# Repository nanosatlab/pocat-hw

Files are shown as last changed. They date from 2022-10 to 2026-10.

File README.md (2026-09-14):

# 3CatNXT PocketQube — Hardware

Hardware repository for the IEEE GRSS PocketQube built at the [NanoSat Lab (UPC)](https://nanosatlab.upc.edu/).

It holds the complete electrical and mechanical design of the satellite: KiCad projects for every
PCB in the stack, the SolidWorks/STEP assembly of the full spacecraft, the deployment mechanisms,
and the ground/mechanical support equipment used to integrate and test it.

This repository contains **design data only** — there is nothing to build or run. Flight and
ground software live elsewhere, as does the PL3 payload hardware
([nanosatlab/pocat-rfi-5g](https://github.com/nanosatlab/pocat-rfi-5g)).

---

## Repository layout

| Path | What it is |
|---|---|
| `pq_eps/` | Electrical Power Subsystem |
| `pq_obc_comms/` | On-Board Computer + COMMS transceiver |
| `pq_adcs/` | Attitude Determination and Control System |
| `pq_pl1/` | Payload 1 interface board |
| `pq_pl2/` | Payload 2 — L-band receiver |
| `pq_topboard/` | +Z face board |
| `pq_botboard/` | −Z face board |
| `pq_latboard/` | Lateral (side) face board |
| `pq_ymag_board/` | +Y magnetorquer board |
| `pq_botnotsobot/` | Deployment-switch / slider board |
| `pq_egse/` | EGSE — electrical ground support equipment breakout |
| `assembly/` | SolidWorks + STEP mechanical assembly of the whole satellite |
| `Vitrina_PQ/` | Display case (acrylic showcase) for the engineering model |

Each KiCad project directory typically contains the `.kicad_sch` / `.kicad_pcb` / `.kicad_pro`
triplet, an exported `.step` for mechanical integration, and a `production/` folder with the IPC
netlist and (where fabricated) Gerbers. Directories suffixed `_old` are superseded revisions kept
for traceability; `pq_pl2/Imports/` holds the original Altium design that PL2 was migrated from.

---

## The boards

The satellite is a stack of 40 × 40 mm boards held between structural face boards that also carry
the solar cells and thermal sensors.

### Stack boards (40 × 40 mm)

**`pq_eps` — Electrical Power Subsystem** · 4-layer, 1.6 mm

Solar energy harvesting through **SPV1040** MPPT boost converters, battery charging and
power-path management by an **LTC4040**, coulomb counting via a **DS2782** fuel gauge, and
regulated rails from an **ISL9120** buck-boost. Carries the kill-switch logic that gates the
main regulator, plus the antenna burn-wire release (`BURNCOMMS`) and per-rail enables for the
ADCS and payloads. Battery is a single Li-ion **LP14430** cell.

**`pq_obc_comms` — On-Board Computer & COMMS** · 4-layer, 1.6 mm

**STM32L476RGT6** microcontroller with a 32 MHz TCXO and a 32.768 kHz RTC crystal, paired with a
**SX1262** sub-GHz LoRa transceiver. RF front end uses a **BGS12PL6** antenna switch out to U.FL
and MS-156C test connectors. The STM32CubeMX pin configuration lives alongside the project in
`STM32L476RG_config/STM32L476RG_config.ioc`, and an interactive BOM is generated at
`pq_obc_comms/bom/ibom.html`.

**`pq_adcs` — Attitude Determination & Control** · 6-layer, 1.6 mm

Sensing from an **IIM-42652** 6-axis IMU and an **MMC5983MA** magnetometer, with sun-sensor
conditioning through **LPV542** op-amps and a **TMUX1108** analog multiplexer.

Two revisions are tracked:
- `PQ_ADCS/` — original design, magnetorquer coils driven by a **BD2606MVV**.
- `PQ_ADCS_HBridge/` — current revision, redesigned around **DRV8214** H-bridge drivers. The
  vendor-supplied symbol, footprint and STEP for the DRV8214 are vendored in
  `PQ_ADCS_HBridge/DRV8214RTER/`.

**`pq_pl2` — L-band receiver payload** · 4-layer, 1.58 mm

Full receive chain: **BFCG162W** LNA → **LEE2-6+** gain stage → **MAX2121** direct-conversion
tuner, with an **LT5537** RF power detector for level monitoring and an **LT3048** ultra-low-noise
LDO feeding the RF section. Clocked by an **ECS-TXO-2016MV** TCXO; MS-156C and U.FL connectors
provide antenna and test access.

**`pq_pl1` — Payload 1 interface** · 2-layer, 1.6 mm

Passive interface/adapter board exposing the stack connector to the PL1 experiment.

### Face and structural boards

**`pq_topboard` / `pq_botboard` / `pq_latboard`** · 2-, 6- and 6-layer respectively

These form the outer faces of the cube. They mount **SLCD-61N8** solar cells and **TCN75A**
digital temperature sensors, and route the harness into the stack. The bottom board additionally
carries **TPS7A7001/7002** LDOs, and the lateral board brings out coaxial connectors for the
deployable antenna. Face boards are 2 mm thick because they are structural.

**`pq_ymag_board`** · 6-layer, 2 mm, 45 × 45 mm

+Y magnetorquer — an air-core coil etched into the PCB, driven from the ADCS board.

**`pq_botnotsobot`** · 2-layer, 1.6 mm, 64 × 58 mm

Slider board carrying the **D2FLA** deployment/kill switches that hold the satellite inert inside
the deployer.

**`pq_egse`** · 6-layer

Electrical Ground Support Equipment. A large breakout fixture that fans every stack connector out
to 0.1" headers so subsystems can be probed, powered and stimulated individually on the bench.
Fabrication Gerbers and drill files are checked in under `pq_egse/manufacturing/`.

---

## Mechanical assembly

`assembly/` is the SolidWorks model of the integrated spacecraft. The top-level assemblies are:

- `ieee_grss_pocketqube.SLDASM` — the full satellite.
- `ieee_grss_pocketqube_beta antena.SLDASM` — variant with the deployed antenna configuration.

Supporting content is organised by subsystem — `eps/`, `adcs/`, `obc&comms/`, `payloads/`,
`structure/`, `lateral/`, `bottom/`, `slider/` — and each PCB folder carries the board as both a
`.step` and a `.SLDPRT`, together with the Edge_Cuts and silkscreen DXF/SVG exports used to keep
the mechanical model in sync with the electrical design.

Of note:

- **`assembly/lateral/antena-deployment/`** — the COMMS tape-spring antenna and its burn-wire
  release: turret, pivot, spring, clip and the resistor that cuts the restraint.
- **`assembly/Lband_Deployment_Mechanism/`** — deployment mechanism for the L-band payload
  antenna (`Lband3d_2res_v7.2.SLDASM`), with its own board and antenna sub-assemblies and a
  `STEP_files/` export set.
- **`assembly/payloads/pl3/`** — RFI-5G payload structure (antenna, supports, SMP interface).
  Mechanical only — the PL3 electrical design lives in its own repository,
  [nanosatlab/pocat-rfi-5g](https://github.com/nanosatlab/pocat-rfi-5g).
- **`assembly/MGSE_Assembly/`** — Mechanical Ground Support Equipment: the jigs and supports used
  to hold the satellite during integration.
- **`assembly/structure/`** — chassis parts plus the screw, nut and spacer library (M2/M3 ISO).

---

## Working with this repository

**Tools.** KiCad 7 or newer is required; the EPS and ADCS H-Bridge projects have been saved with a
more recent file format (`20260206`) than the rest of the stack, so opening them in an older KiCad
will fail. Mechanical files are SolidWorks, with STEP exports provided for anyone without it.

**Exports are checked in on purpose.** STEP files, Edge_Cuts/silkscreen DXFs and `production/`
netlists are tracked so that mechanical integration and manufacturing can proceed without
re-running KiCad. If you change a board outline or a connector position, re-export the STEP and
DXF and commit them in the same change — otherwise the mechanical assembly silently drifts out of
date.

**What is ignored.** `.gitignore` excludes KiCad backups, autosaves, lock files, netlists, and
generated BOM `.csv`/`.xml`. Note that it also ignores `production/` and `*-backups/` directories
by default; the ones present in the repository were committed before those rules were added and
remain tracked.

**Branching.** Work happens on per-subsystem branches (`eps_updated`, `adcs_hbridge_revision`,
`Lateral_and_bottom_connectors`, …) which are merged into `main` once the revision passes review.
Binary CAD files do not merge — coordinate before two people edit the same board.

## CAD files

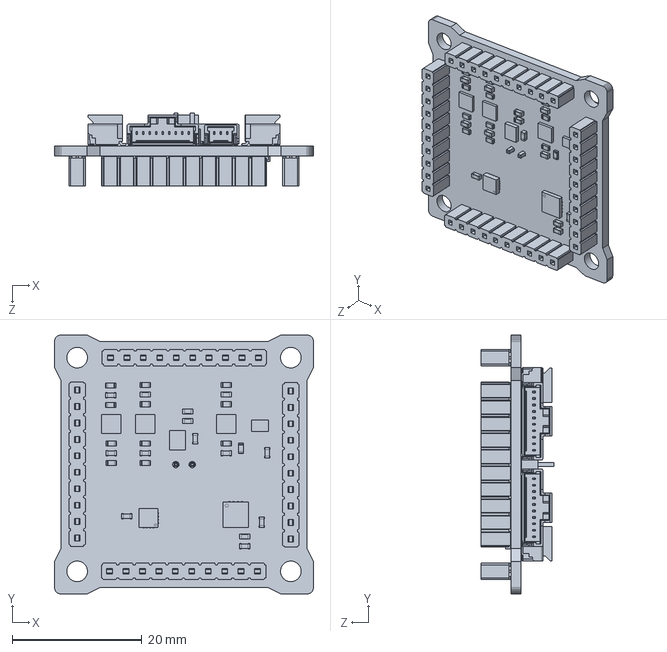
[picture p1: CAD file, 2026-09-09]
assembly/adcs/pq-adcs.SLDPRT
40.0 x 40.0 x 11.3 mm

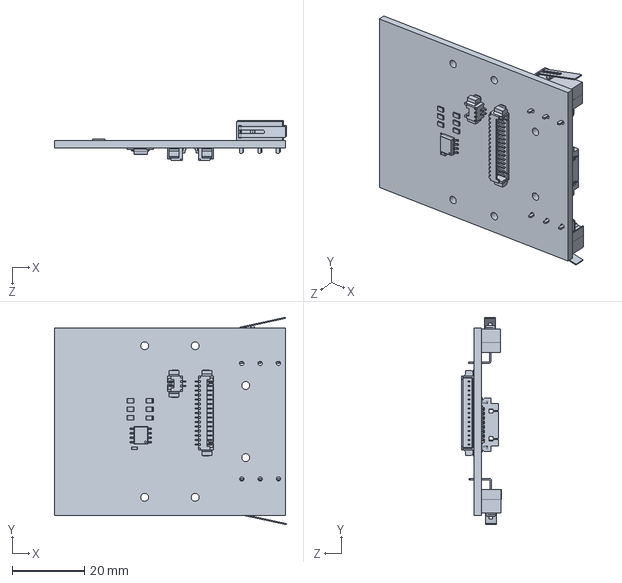
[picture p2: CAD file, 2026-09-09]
assembly/bottom/pq-bottom.SLDPRT
64.3 x 57.5 x 11.0 mm

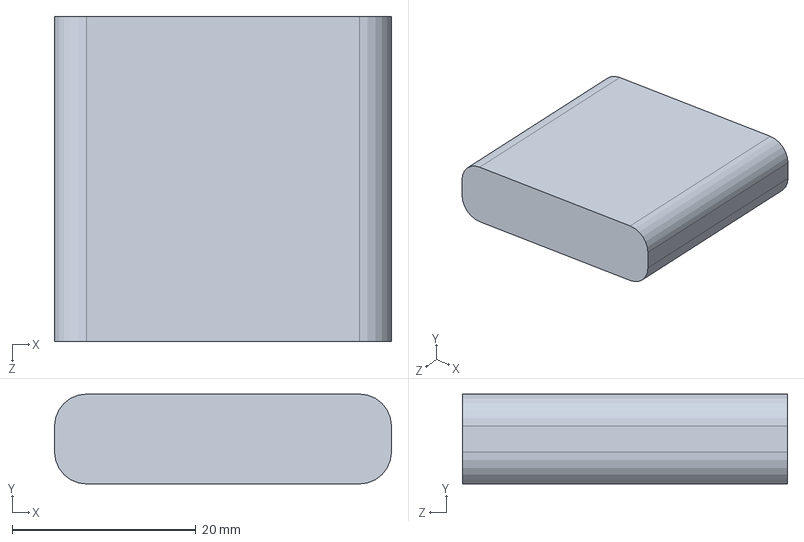
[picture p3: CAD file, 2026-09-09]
assembly/eps/battery/Battery.SLDPRT
36.7 x 9.80 x 35.4 mm

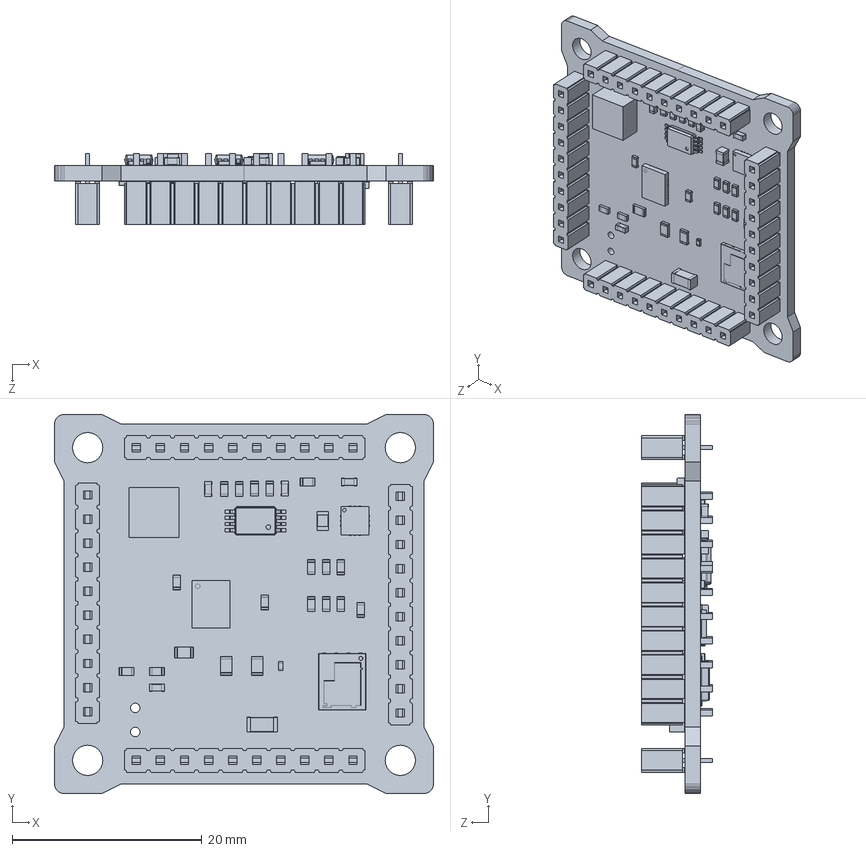
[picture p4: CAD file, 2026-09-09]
assembly/eps/eps-board/pq_eps.SLDPRT
40.0 x 40.0 x 7.52 mm

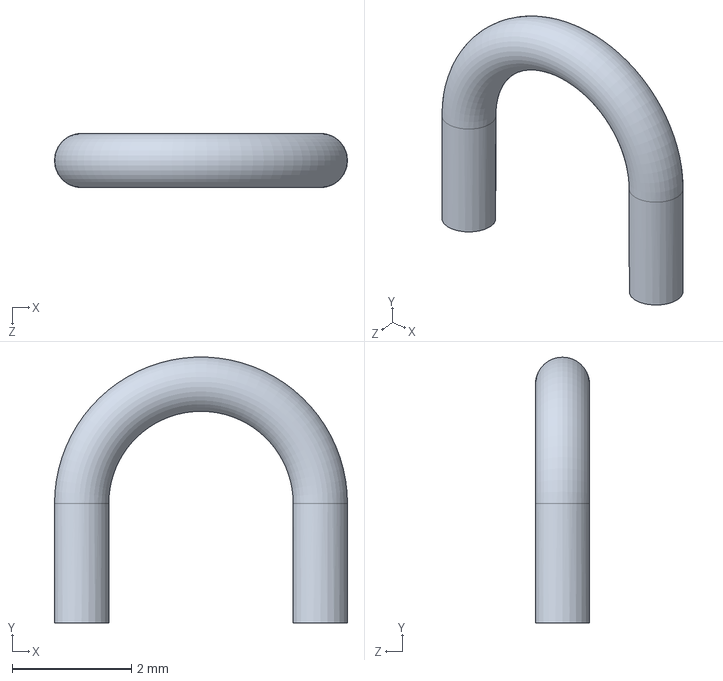
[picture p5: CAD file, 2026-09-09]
assembly/lateral/antena-deployment/JumperTHT Deployment.SLDPRT
4.91 x 4.45 x 0.91 mm

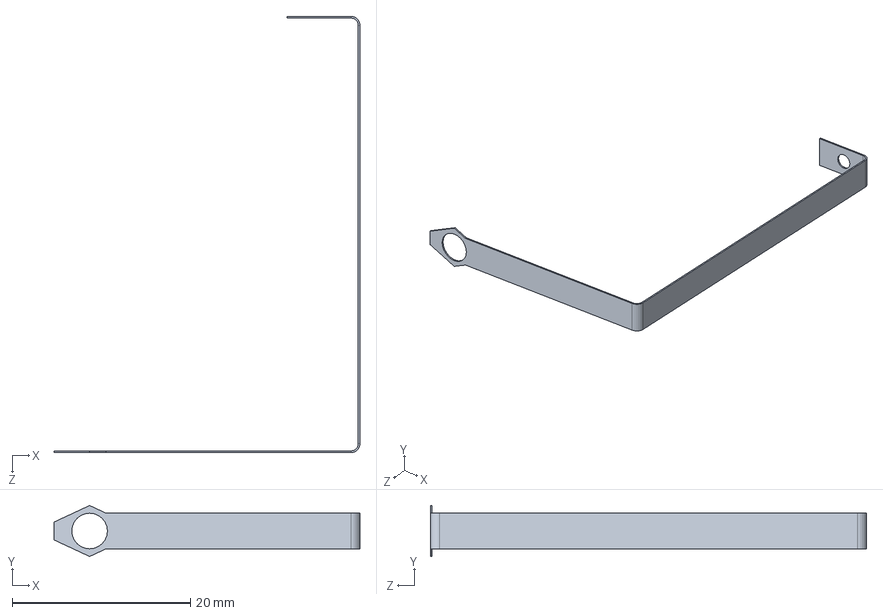
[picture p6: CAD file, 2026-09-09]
assembly/lateral/antenna/Antenna_Tape_Sheet.SLDPRT
34.4 x 5.73 x 49.0 mm

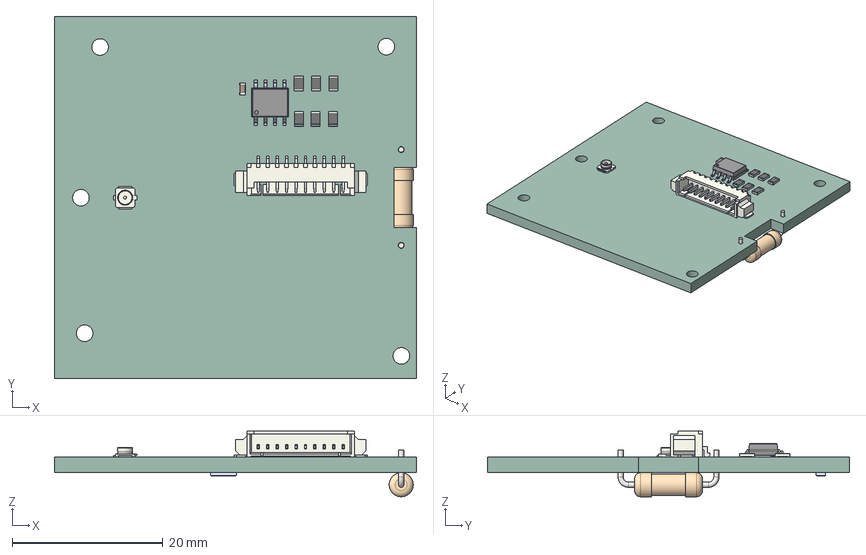
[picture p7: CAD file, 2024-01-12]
assembly/lateral/lateral-board/PQ_Lat_Board.step
48.0 x 48.0 x 8.70 mm
R_0805_2012Metric x 6
Molex_53261_1071
ASSEMBLY
C_0603_1608Metric
U.FL_Hirose_U.FL-R-SMT-1_Vertical
SLCD-61N8
R_Axial_DIN0309_L90mm_D32mm_P1270mm_Horizontal
PQ_Lat_Board PCB

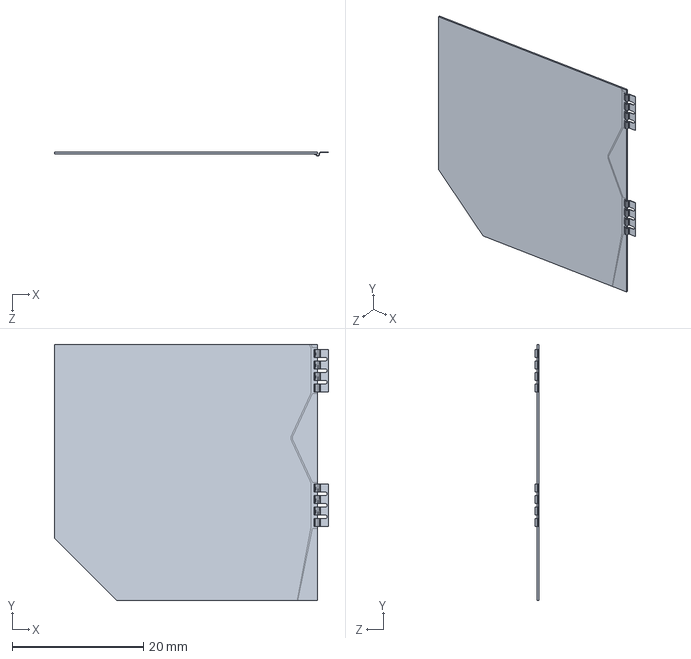
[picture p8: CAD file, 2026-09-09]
assembly/lateral/solar-cells/Solar_Cell_Azur.SLDPRT
41.7 x 39.0 x 0.61 mm

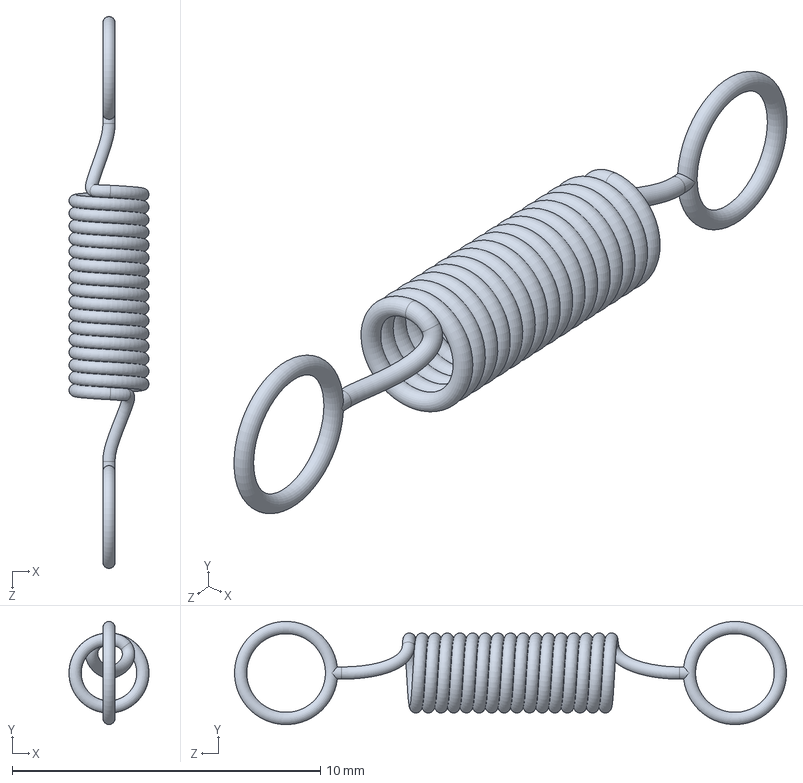
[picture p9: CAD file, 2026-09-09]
assembly/Lband_Deployment_Mechanism/AntennaDeployment_elements/Muelle.SLDPRT
2.60 x 3.34 x 17.9 mm

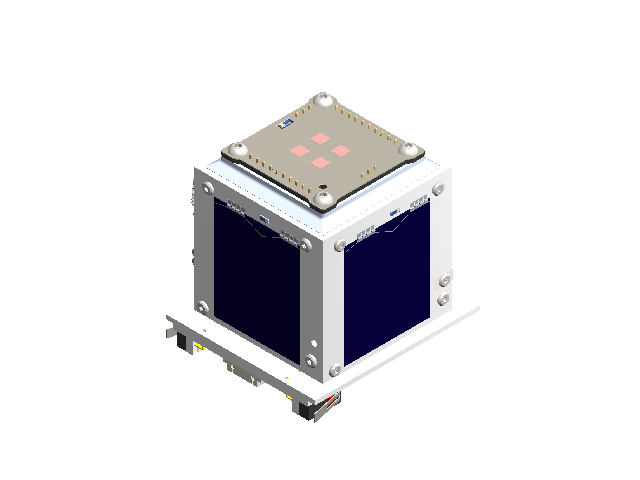
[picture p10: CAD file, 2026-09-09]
assembly/ieee_grss_pocketqube_beta antena.SLDASM
Support_Bot
PQ-STRUCTURE-M3_Spacer_Round x 3
PQ_Screw_ISO-14580 x 6
BN 20146 3233654 hexalobular socket head cap screw M2x5 x 22
Battery
pq_eps
pq-adcs
PQ_MagYBoard
pq_obc_comms
pq-slider
pq-bottom
PQ_Lat_Board x 4
Solar_Cell_Azur x 5
RFI-5G_Support_v2
RFI-5G_RF_Top
RFI-5G_SupportFR4
RFI-5G_RF_Antenna
SMP-FS2A-860
RFI-5G_RF_Bottom
RFI-5G_Interface
screw_iso_7380-m3x8-12_9 x 4
PivoTurret Deployment
hex thin nut chamfered gradeab_iso
Antenna_comms
Clip Deployment
Screw Low M2x4 Deployment
Jumper Deployment
Resistencia Deployment x 2
Muelle Deployment
Turret Deployment
JumperTHT Deployment

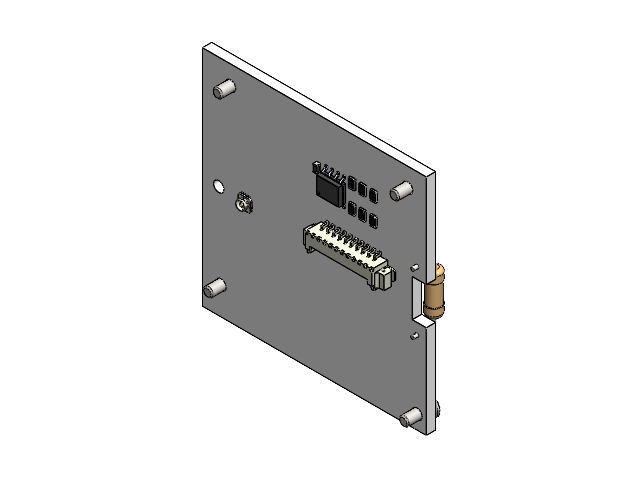
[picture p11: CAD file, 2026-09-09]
assembly/lateral/pq-lateral-assembly.SLDASM
PQ_Lat_Board
BN 20146 3233654 hexalobular socket head cap screw M2x5 x 4
Solar_Cell_Azur

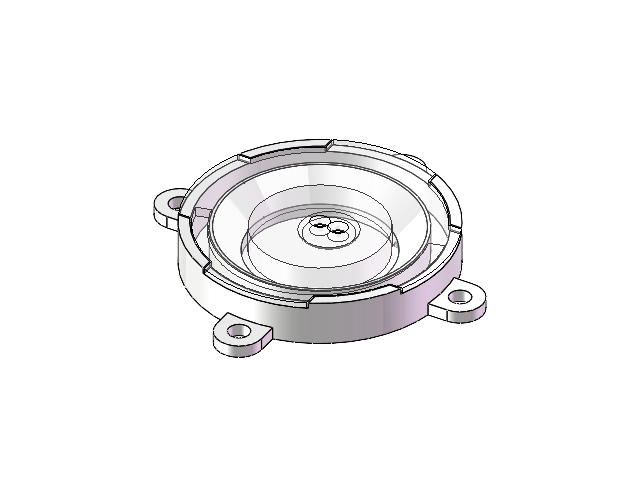
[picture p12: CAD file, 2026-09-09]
assembly/Lband_Deployment_Mechanism/Payload_v7/Payload_ensamblaje.SLDASM
Base
Tapa

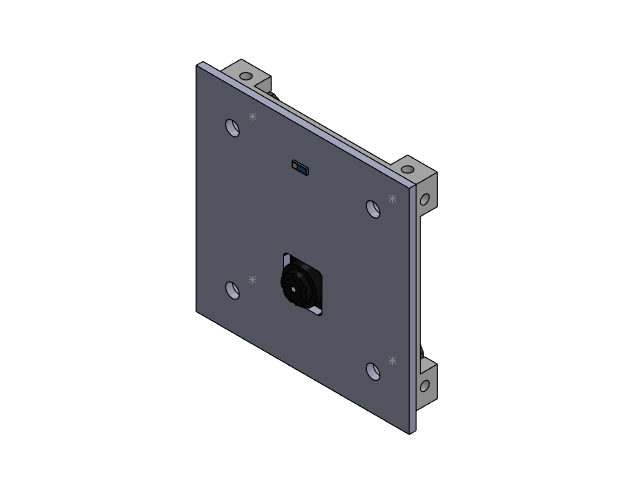
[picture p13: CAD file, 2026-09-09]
assembly/payloads/pl1/pl1.SLDASM
pq-pl1
Support_Top
PQ-STRUCTURE-M3_Spacer_Round x 4
pq-pl1-top

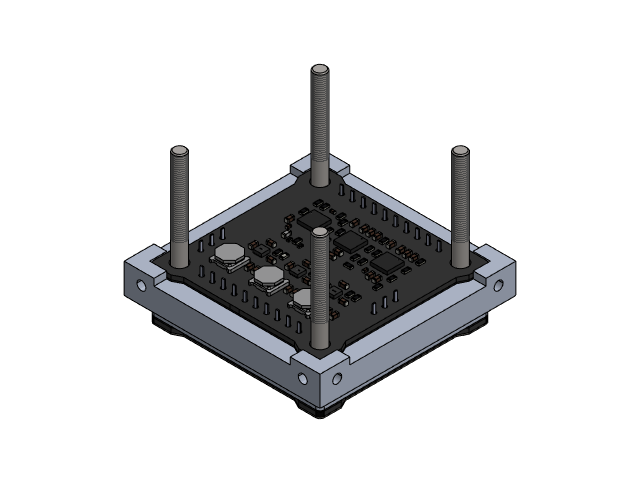
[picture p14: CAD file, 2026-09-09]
assembly/payloads/pl3/pl3.SLDASM
RFI-5G_Support_v2
RFI-5G_RF_Top
RFI-5G_SupportFR4
RFI-5G_RF_Antenna
SMP-FS2A-860
RFI-5G_RF_Bottom
RFI-5G_Interface
screw_iso_7380-m3x8-12_9 x 4

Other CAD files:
assembly/ieee_grss_pocketqube.SLDASM
assembly/Lband_Deployment_Mechanism/Board_elements/BBL-101-G-E_1.SLDASM
Vitrina_PQ/Vitrina_PQ_Assembly.SLDASM
assembly/Lband_Deployment_Mechanism/Board_elements/TCN75AVOA713_1.SLDASM
Vitrina_PQ/acrylic_laser_cutting_design.dxf
Vitrina_PQ/base.SLDPRT
Vitrina_PQ/metacrilat_curt.SLDPRT
Vitrina_PQ/metacrilat_llarg.SLDPRT
Vitrina_PQ/metacrilat_tapa.SLDPRT
assembly/Lband_Deployment_Mechanism/AntennaDeployment_elements/5108N949_Music Wire Steel Extension Spring with Loop Ends (1).SLDPRT
assembly/Lband_Deployment_Mechanism/AntennaDeployment_elements/5108N95_Music Wire Steel Extension Spring with Loop Ends.SLDPRT
assembly/Lband_Deployment_Mechanism/AntennaDeployment_elements/96605K31_Galvanized Spring-Tempered Steel Extension Spring.SLDPRT
assembly/Lband_Deployment_Mechanism/AntennaDeployment_elements/Antena.SLDPRT
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

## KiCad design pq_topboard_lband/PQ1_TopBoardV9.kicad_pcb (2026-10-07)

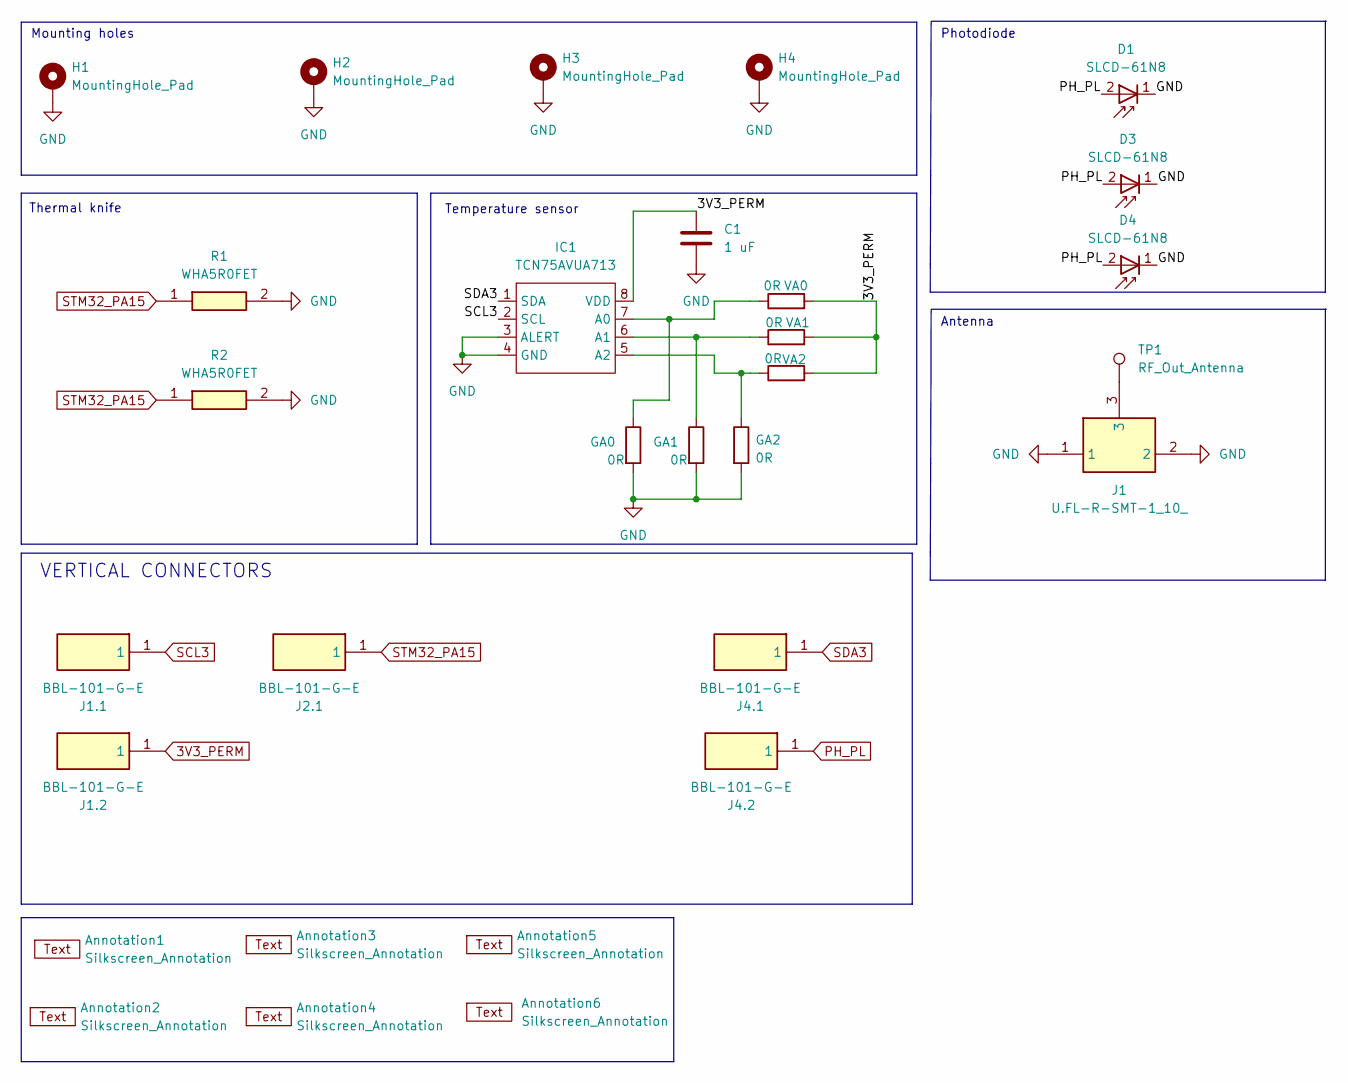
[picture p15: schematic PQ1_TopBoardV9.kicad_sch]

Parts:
Annotation1: Silkscreen_Annotation; IEEE_logo
Annotation2: Silkscreen_Annotation; GRSS
Annotation3: Silkscreen_Annotation; NSL_long
Annotation4: Silkscreen_Annotation; Telecos
Annotation5: Silkscreen_Annotation; UPC_positiu
Annotation6: Silkscreen_Annotation; NSL_Lektron
C1: 1 uF; C_0603_1608Metric; Manufacturer Part Numbe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 GRM188R72A104KA35J
D1, D3, D4: SLCD-61N8; Manufacturer Part Numbe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 SLCD-61N8
GA0, GA1, GA2: 0R; R_0805_2012Metric; Manufacturer Part Numbe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 CRCW08055K00JNTA
H1, H2, H3, H4: MountingHole_Pad; MountingHole_3.2mm_M3_ISO14580_Pad; Manufacturer Part Numbe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 N/A
IC1: TCN75AVUA713; TCN75AVOA; Manufacturer Part Numbe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 TCN75AVOA
J1: U.FL-R-SMT-1_10_; Mouser Part Number 798-U.FL-R-SMT-110
J1.1, J1.2, J2.1, J4.1, J4.2: BBL-101-G-E; BBL-101-Y-X; Mouser Part Number 200-BBL101GE
R1, R2: WHA5R0FET; RESAD1524W60L508D254; Mouser Part Number 588-WHA5R0FET
TP1: RF_Out_Antenna; TestPoint_Keystone_5015_Micro_Mini
VA0, VA1, VA2: 0R; R_0805_2012Metric; Manufacturer Part Numbe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 CRCW08055K00JNTA

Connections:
3V3_PERM: C1.1, IC1.8 (VDD), J1.2.1 (1_1), VA0.2, VA1.2, VA2.2
GND: C1.2, D1.1, D3.1, D4.1, GA0.2, GA1.2, GA2.2, H1.1 (1_1), H2.1 (1_1), H3.1 (1_1), H4.1 (1_1), IC1.3 (ALERT), IC1.4 (GND), J1.1, J1.2, R1.2, R2.2
unnamed: GA0.1, IC1.7 (A0), VA0.1
unnamed: GA1.1, IC1.6 (A1), VA1.1
unnamed: GA2.1, IC1.5 (A2), VA2.1
unnamed: J1.3, TP1.1 (1_1)
PH_PL: D1.2, D3.2, D4.2, J4.2.1 (1_1)
SCL3: IC1.2 (SCL), J1.1.1 (1_1)
SDA3: IC1.1 (SDA), J4.1.1 (1_1)
STM32_PA15: J2.1.1 (1_1), R1.1, R2.1

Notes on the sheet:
Photodiode
VERTICAL CONNECTORS
Thermal knife
Mounting holes
Antenna
Temperature sensor

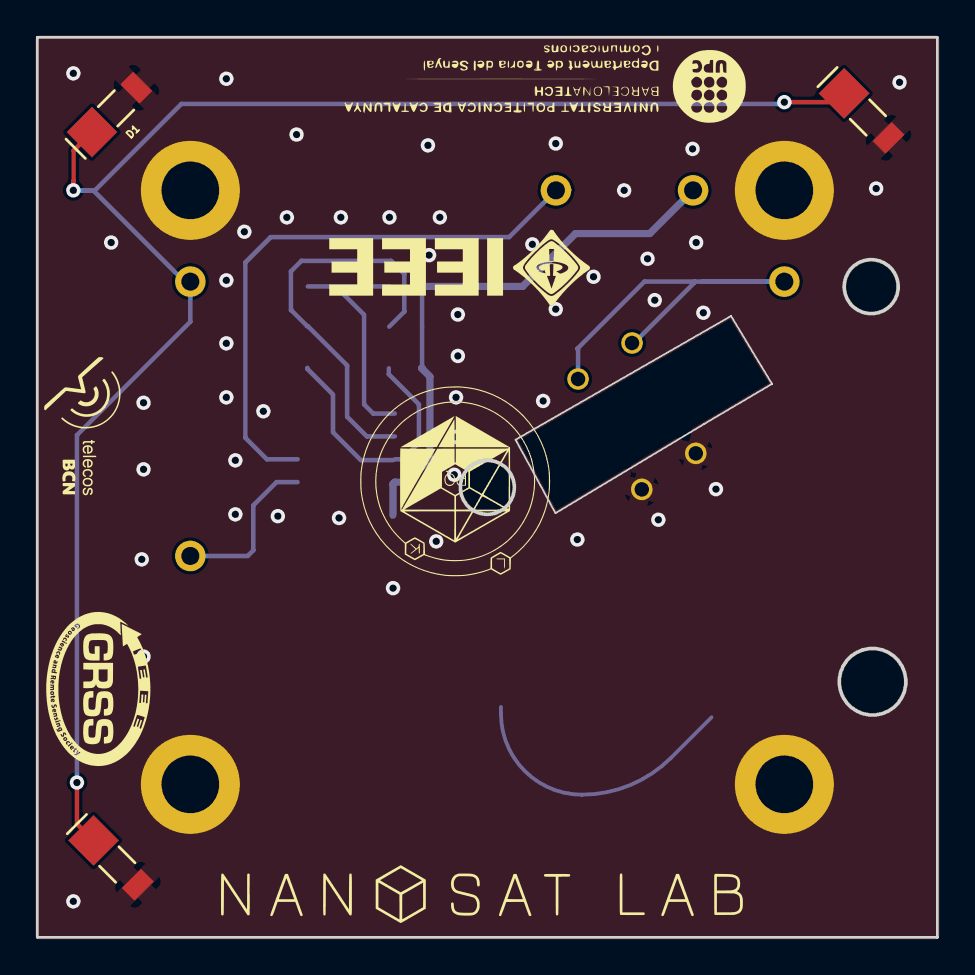
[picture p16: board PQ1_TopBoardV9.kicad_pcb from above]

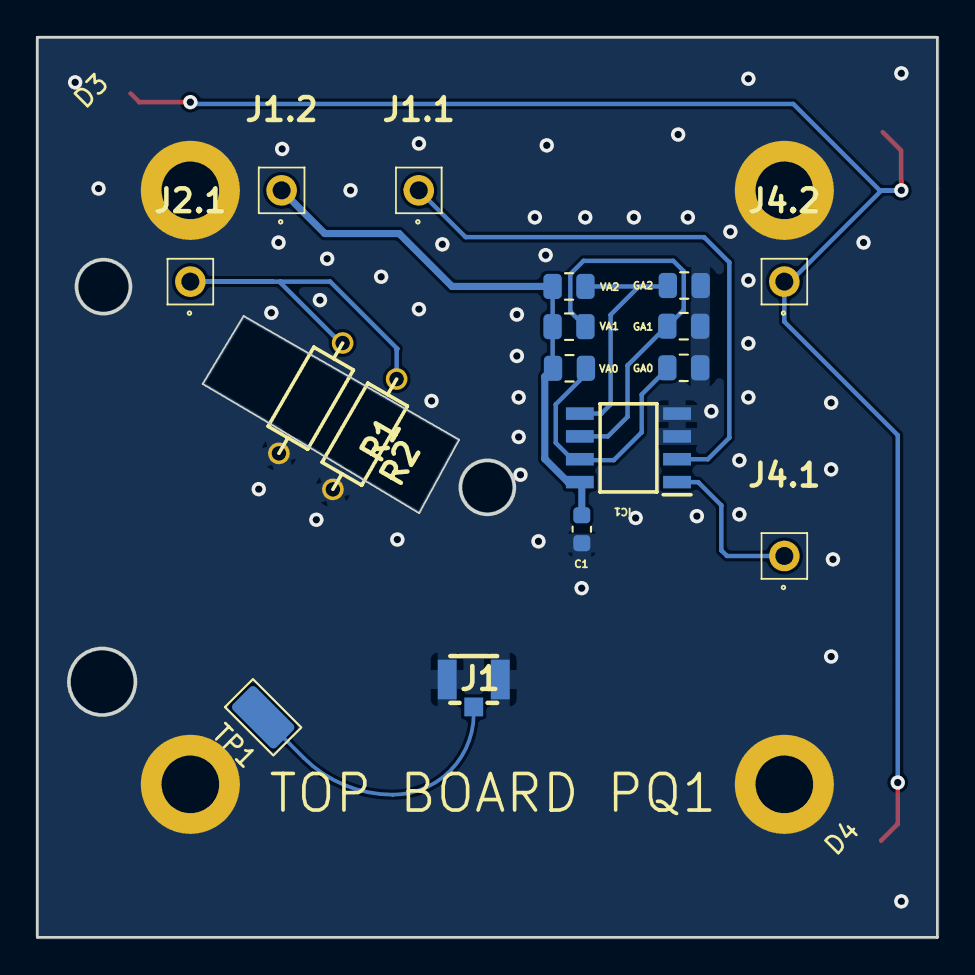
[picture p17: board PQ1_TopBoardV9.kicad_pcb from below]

Board: 2 copper layers, 50.0 x 50.0 mm, 30 parts (17 on the bottom side), 10 nets.

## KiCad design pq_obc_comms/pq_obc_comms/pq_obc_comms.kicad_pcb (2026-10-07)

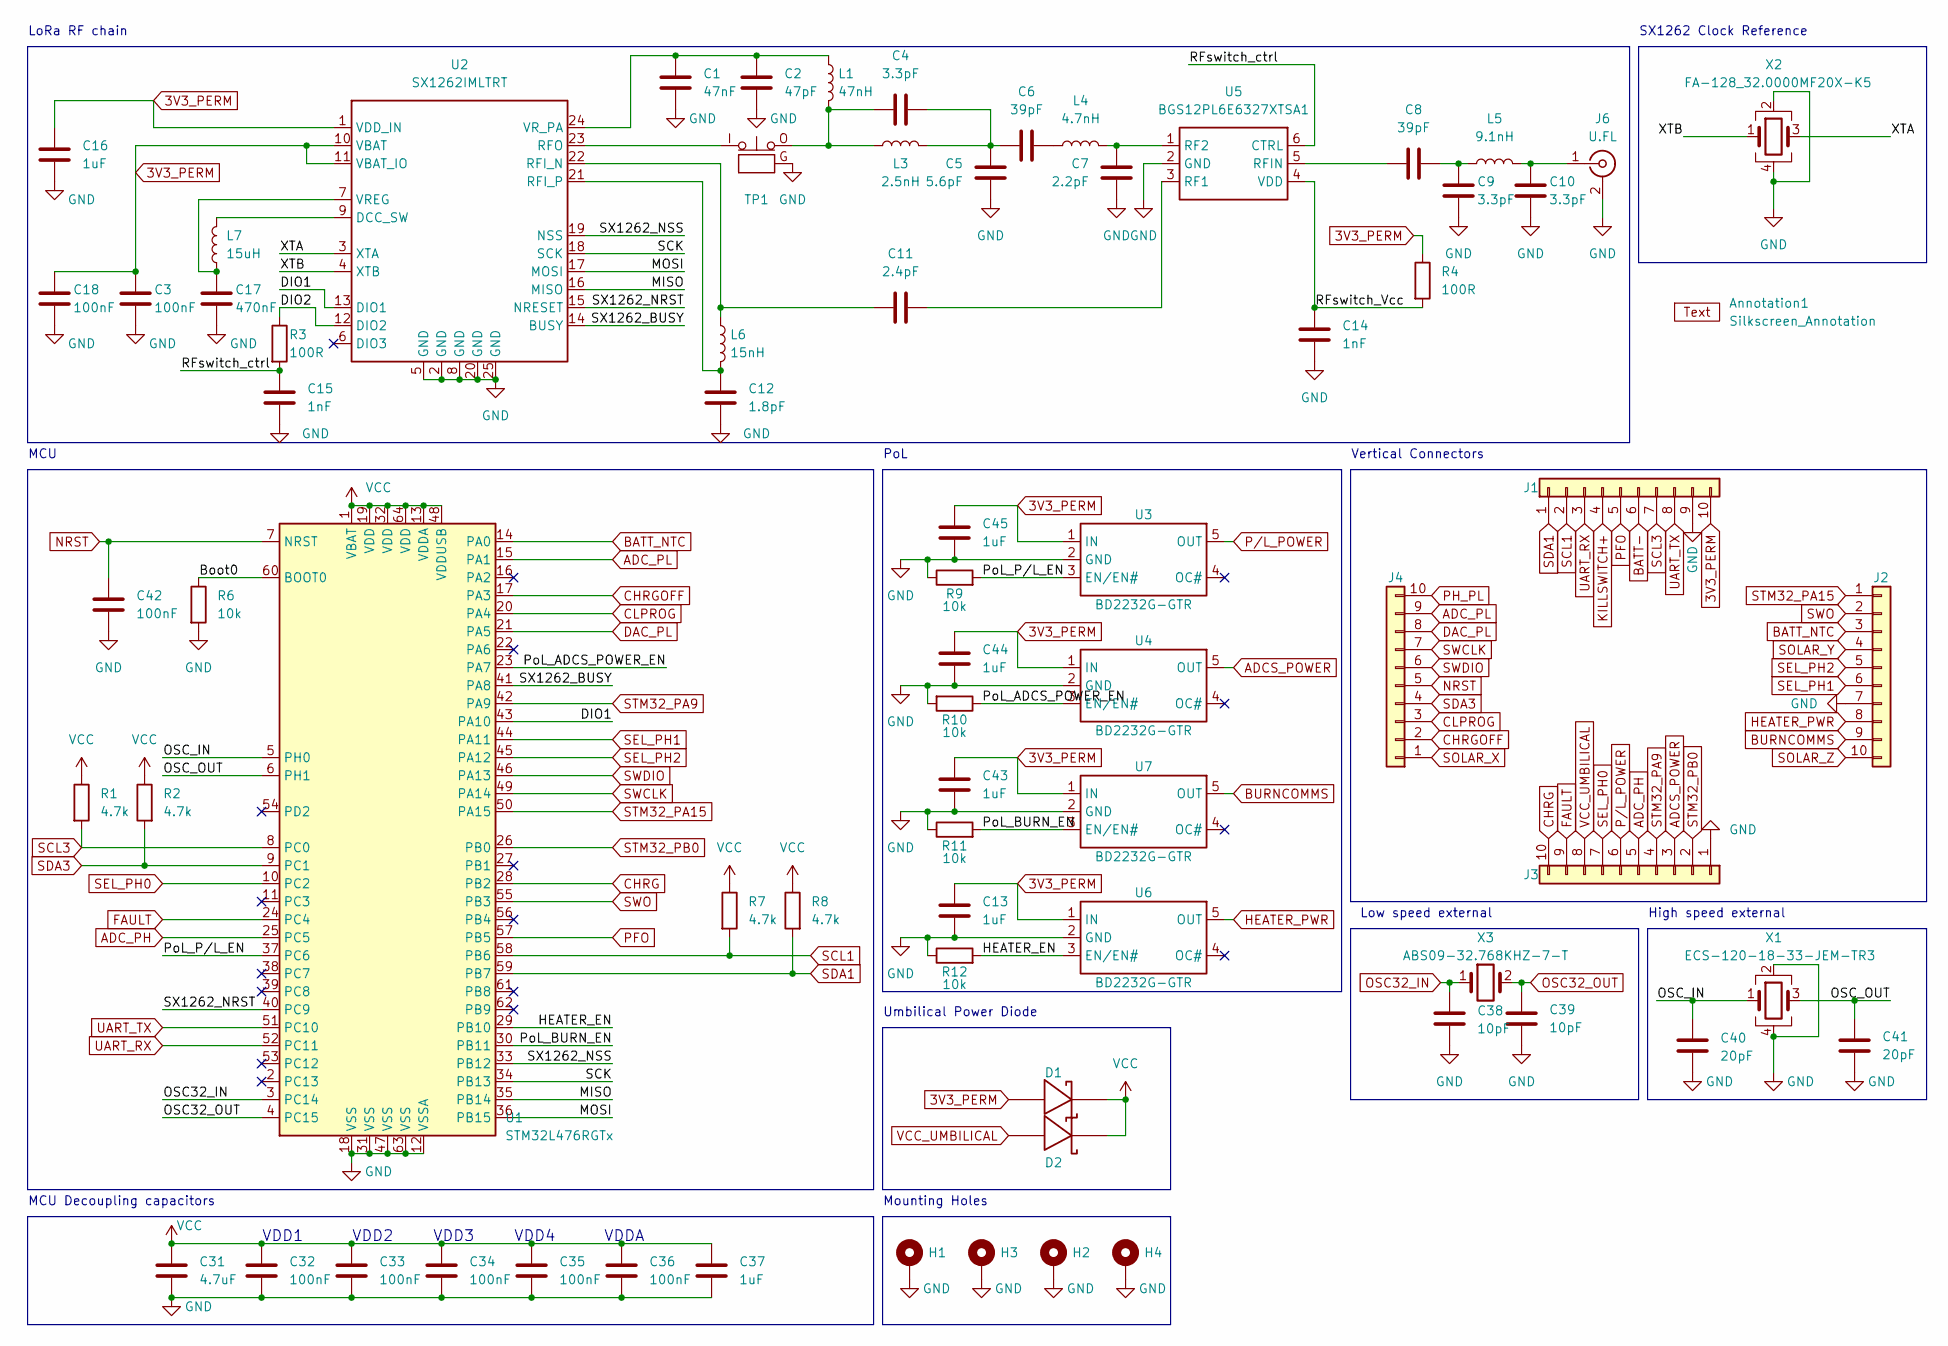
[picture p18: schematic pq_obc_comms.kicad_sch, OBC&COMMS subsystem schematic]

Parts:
Annotation1: Silkscreen_Annotation; Bike
C1: 47nF; C_0402_1005Metric; Manufacturer Part Numbe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 GRM155R71C473KA01J
C2: 47pF; C_0402_1005Metric; Manufacturer Part Numbe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 GJM1555C1H470JB01J
C3, C18, C32, C33, C34, C35, C36, C42: 100nF; C_0603_1608Metric; Manufacturer Part Numbe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 GRM188R72A104KA35J
C4, C9, C10: 3.3pF; C_0402_1005Metric; Manufacturer Part Numbe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 600L3R3BT200T
C5: 5.6pF; C_0402_1005Metric; Manufacturer Part Numbe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 600L5R6BTN200T
C6, C8: 39pF; C_0402_1005Metric; Manufacturer Part Numbe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 GJM1555C1H390FB01D
C7: 2.2pF; C_0402_1005Metric; Manufacturer Part Numbe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 600L2R2BT200T
C11: 2.4pF; C_0402_1005Metric; Manufacturer Part Numbe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 600L2R4BW200T
C12: 1.8pF; C_0402_1005Metric; Manufacturer Part Numbe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 600L1R8BW200T
C13, C16, C37, C43, C44, C45: 1uF; C_0603_1608Metric; Manufacturer Part Numbe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 GRM188R61A105KA61D
C14, C15: 1nF; C_0603_1608Metric; Manufacturer Part Numbe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 0603B102K500CT
C17: 470nF; C_0603_1608Metric; Manufacturer Part Numbe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 GRM188R7YA474KE05D
C31: 4.7uF; C_0603_1608Metric; Manufacturer Part Numbe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 GRT188R61E475KE13D
C38, C39: 10pF; C_0603_1608Metric; Manufacturer Part Numbe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 06035A100GAT2A
C40, C41: 20pF; C_0603_1608Metric; Manufacturer Part Numbe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 GCM1885C2A200JA16D
D1, D2: type="D" model="RBS1LAM40ATR" lib=""; RBS1LAM40ATR_Schottky; Manufacturer Part Numbe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 RBS1LAM40ATR
H1, H2, H3, H4: MountingHole_Pad; MountingHole_3.2mm_M3_Pad
J1, J2, J3, J4: Conn_01x10; SLW-110-01; Manufacturer Part Numbe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 CES-110-01-T-S
J6: U.FL; U.FL_Hirose_U.FL-R-SMT-1_Vertical; Manufacturer Part Numbe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 U.FL-R-SMT-1(10)
L1: 47nH; L_0402_1005Metric; Manufacturer Part Numbe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 0402DC-47NXGRW
L3: 2.5nH; L_0402_1005Metric; Manufacturer Part Numbe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 LQW15AN2N5B00D
L4: 4.7nH; L_0402_1005Metric; Manufacturer Part Numbe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 0402DC-4N7XGRW
L5: 9.1nH; L_0402_1005Metric; Manufacturer Part Numbe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 LQW15AN9N1G8ZD
L6: 15nH; L_0402_1005Metric; Manufacturer Part Numbe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 LQW15AN15NH00D
L7: 15uH; L_0805_2012Metric; Manufacturer Part Numbe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 LQM21DN150M70L
R1, R2, R7, R8: 4.7k; R_0603_1608Metric; Manufacturer Part Numbe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 CRCW06034K70JNEAC
R3, R4: 100R; R_0603_1608Metric; Manufacturer Part Numbe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 RC0603JR-07100RL
R6, R9, R10, R11, R12: 10k; R_0402_1005Metric; Manufacturer Part Numbe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 CRCW040220K0FKEDC
TP1: CoaxialSwitch_Testpoint; CoaxialSwitch_Hirose_MS-156C3_Horizontal; Manufacturer Part Numbe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 MS-156C3(20)
U1: STM32L476RGTx; LQFP-64_10x10mm_P0.5mm; Manufacturer Part Numbe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 STM32L476RGT6
U2: SX1262IMLTRT; QFN-24-1EP_4x4mm_P0.5mm_EP2.6x2.6mm; Manufacturer Part Numbe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 SX1262IMLTRT
U3, U4, U6, U7: BD2232G-GTR; SOT-23-5; Manufacturer Part Numbe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 BD2232G-GTR
U5: BGS12PL6E6327XTSA1; PG-TSLP-6-4; Manufacturer Part Numbe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 BGS12PL6E6327XTSA1
X1: ECS-120-18-33-JEM-TR3; ECS-120-18-33; Manufacturer Part Numbe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 ECS-120-18-33-JEM-TR3
X2: FA-128_32.0000MF20X-K5; EPSON_FA128; Manufacturer Part Numbe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 FA-128 32.0000MF20X-K5
X3: ABS09-32.768KHZ-7-T; ABS09; Manufacturer Part Numbe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 ABS09-32.768KHZ-7-T

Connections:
3V3_PERM: C3.1, C13.1, C16.1, C18.1, C43.1, C44.1, C45.2, D1.2, J1.10, R4.1, U2.1 (VDD_IN), U2.10 (VBAT), U2.11 (VBAT_IO), U3.1 (IN), U4.1 (IN), U6.1 (IN), U7.1 (IN)
/Boot0: R6.1, U1.60 (BOOT0)
/DIO1: U1.43 (PA10), U2.13 (DIO1)
/DIO2: R3.1, U2.12 (DIO2)
/HEATER_EN: R12.2, U1.29 (PB10), U6.3 (EN/EN#)
/MISO: U1.35 (PB14), U2.16 (MISO)
/MOSI: U1.36 (PB15), U2.17 (MOSI)
/OSC_IN: C40.1, U1.5 (PH0), X1.1
/OSC_OUT: C41.1, U1.6 (PH1), X1.3
/PoL_ADCS_POWER_EN: R10.1, U1.23 (PA7), U4.3 (EN/EN#)
/PoL_BURN_EN: R11.2, U1.30 (PB11), U7.3 (EN/EN#)
/PoL_P/L_EN: R9.2, U1.37 (PC6), U3.3 (EN/EN#)
/RFswitch_Vcc: C14.1, R4.2, U5.4 (VDD)
/RFswitch_ctrl: C15.1, R3.2, U5.6 (CTRL)
/SCK: U1.34 (PB13), U2.18 (SCK)
/SX1262_BUSY: U1.41 (PA8), U2.14 (BUSY)
/SX1262_NRST: U1.40 (PC9), U2.15 (NRESET)
/SX1262_NSS: U1.33 (PB12), U2.19 (NSS)
/XTA: U2.3 (XTA), X2.3
/XTB: U2.4 (XTB), X2.1
ADCS_POWER: J3.3, U4.5 (OUT)
ADC_PH: J3.5, U1.25 (PC5)
ADC_PL: J4.9, U1.15 (PA1)
BATT-: J1.6
BATT_NTC: J2.3, U1.14 (PA0)
BURNCOMMS: J2.9, U7.5 (OUT)
CHRG: J3.10, U1.28 (PB2)
CHRGOFF: J4.2, U1.17 (PA3)
CLPROG: J4.3, U1.20 (PA4)
DAC_PL: J4.8, U1.21 (PA5)
FAULT: J3.9, U1.24 (PC4)
GND: C1.2, C2.2, C3.2, C5.2, C7.2, C9.2, C10.2, C12.2, C13.2, C14.2, C15.2, C16.2, C17.2, C18.2, C31.2, C32.2, C33.2, C34.2, C35.2, C36.2, C37.2, C38.2, C39.2, C40.2, C41.2, C42.2, C43.2, C44.2, C45.1, H1.1 (1_1), H2.1 (1_1), H3.1 (1_1), H4.1 (1_1), J1.9, J2.7, J3.1, J6.2 (Ext), R6.2, R9.1, R10.2, R11.1, R12.1, TP1.G, U1.12 (VSSA), U1.18 (VSS), U1.31 (VSS), U1.47 (VSS), U1.63 (VSS), U2.2 (GND), U2.5 (GND), U2.8 (GND), U2.20 (GND), U2.25 (GND), U3.2 (GND), U4.2 (GND), U5.2 (GND), U6.2 (GND), U7.2 (GND), X1.2, X1.4, X2.2, X2.4
HEATER_PWR: J2.8, U6.5 (OUT)
KILLSWITCH+: J1.4
NRST: C42.1, J4.5, U1.7 (NRST)
unnamed: C4.1, L1.2, L3.1, TP1.O
unnamed: C4.2, C5.1, C6.1, L3.2
unnamed: C6.2, L4.1
unnamed: C8.2, C9.1, L5.1
unnamed: C10.1, J6.1 (In), L5.2
unnamed: L7.2, U2.9 (DCC_SW)
unnamed: C11.1, L6.1, U2.22 (RFI_N)
unnamed: C12.1, L6.2, U2.21 (RFI_P)
unnamed: TP1.I, U2.23 (RFO)
unnamed: C17.1, L7.1, U2.7 (VREG)
unnamed: C1.1, C2.1, L1.1, U2.24 (VR_PA)
unnamed: C11.2, U5.3 (RF1)
unnamed: C7.1, L4.2, U5.1 (RF2)
unnamed: C8.1, U5.5 (RFIN)
OSC32_IN: C38.1, U1.3 (PC14), X3.1
OSC32_OUT: C39.1, U1.4 (PC15), X3.2
PFO: J1.5, U1.57 (PB5)
PH_PL: J4.10
SCL1: J1.2, R7.2, U1.58 (PB6)
SCL3: J1.7, R1.2, U1.8 (PC0)
SDA1: J1.1, R8.2, U1.59 (PB7)
SDA3: J4.4, R2.2, U1.9 (PC1)
SEL_PH0: J3.7, U1.10 (PC2)
SEL_PH1: J2.6, U1.44 (PA11)
SEL_PH2: J2.5, U1.45 (PA12)
SOLAR_X: J4.1
SOLAR_Y: J2.4
SOLAR_Z: J2.10
STM32_PA9: J3.4, U1.42 (PA9)
STM32_PA15: J2.1, U1.50 (PA15)
STM32_PB0: J3.2, U1.26 (PB0)
SWCLK: J4.7, U1.49 (PA14)
SWDIO: J4.6, U1.46 (PA13)
SWO: J2.2, U1.55 (PB3)
UART_RX: J1.3, U1.52 (PC11)
UART_TX: J1.8, U1.51 (PC10)
VCC: C31.1, C32.1, C33.1, C34.1, C35.1, C36.1, C37.1, D1.1, D2.1, R1.1, R2.1, R7.1, R8.1, U1.1 (VBAT), U1.13 (VDDA), U1.19 (VDD), U1.32 (VDD), U1.48 (VDDUSB), U1.64 (VDD)
VCC_UMBILICAL: D2.2, J3.8

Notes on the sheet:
VDD2
MCU Decoupling capacitors
LoRa RF chain
SX1262 Clock Reference
Umbilical Power Diode
VDD1
Low speed external
Vertical Connectors
MCU
VDD3
VDDA
High speed external
Mounting Holes
VDD4
PoL

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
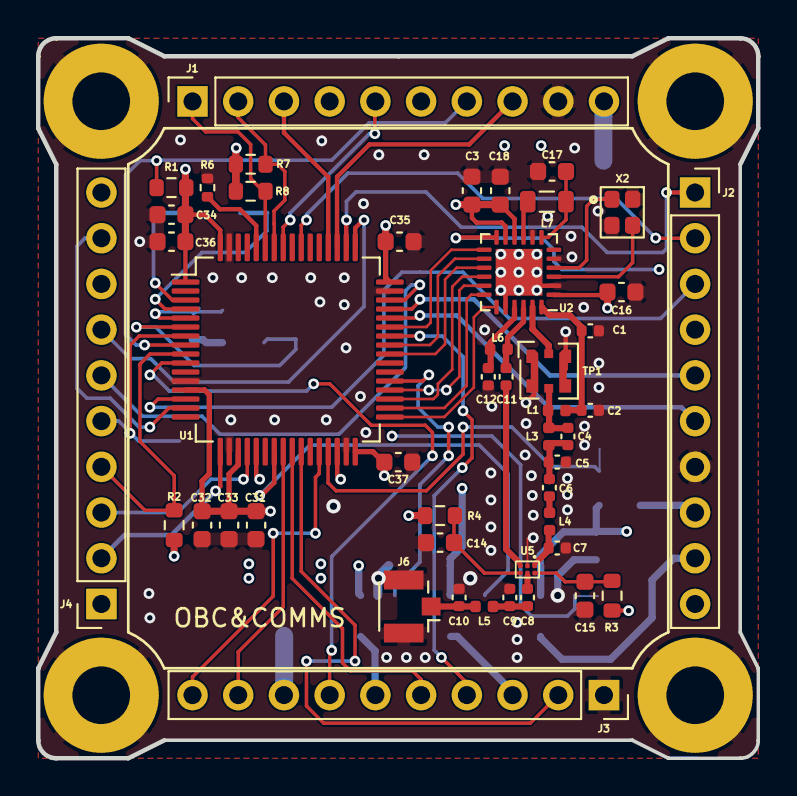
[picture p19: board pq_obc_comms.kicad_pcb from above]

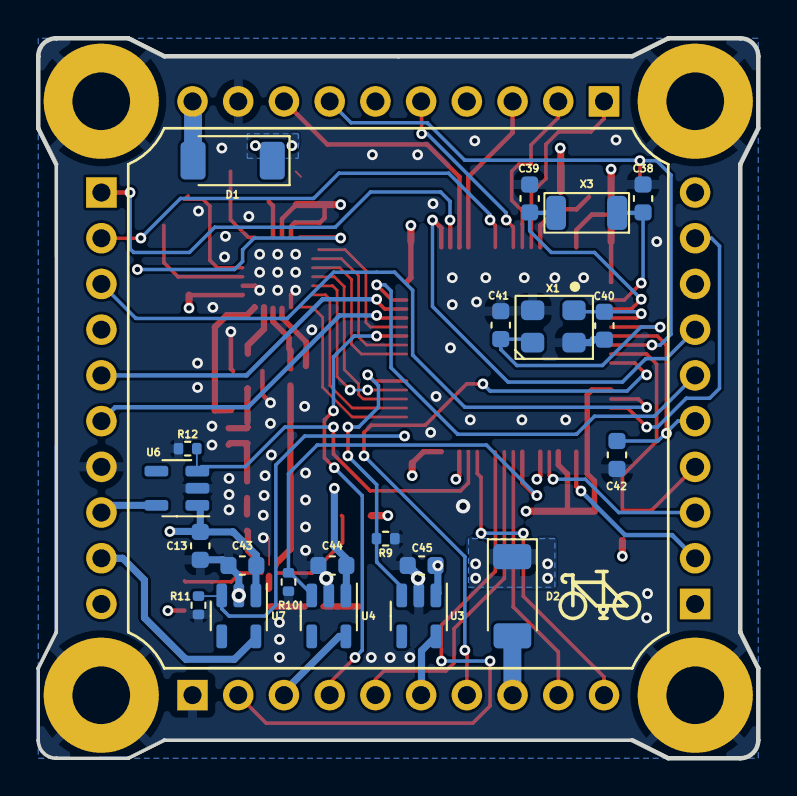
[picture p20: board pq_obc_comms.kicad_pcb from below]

Board: 4 copper layers, 40.0 x 40.0 mm, 73 parts (22 on the bottom side), 68 nets.

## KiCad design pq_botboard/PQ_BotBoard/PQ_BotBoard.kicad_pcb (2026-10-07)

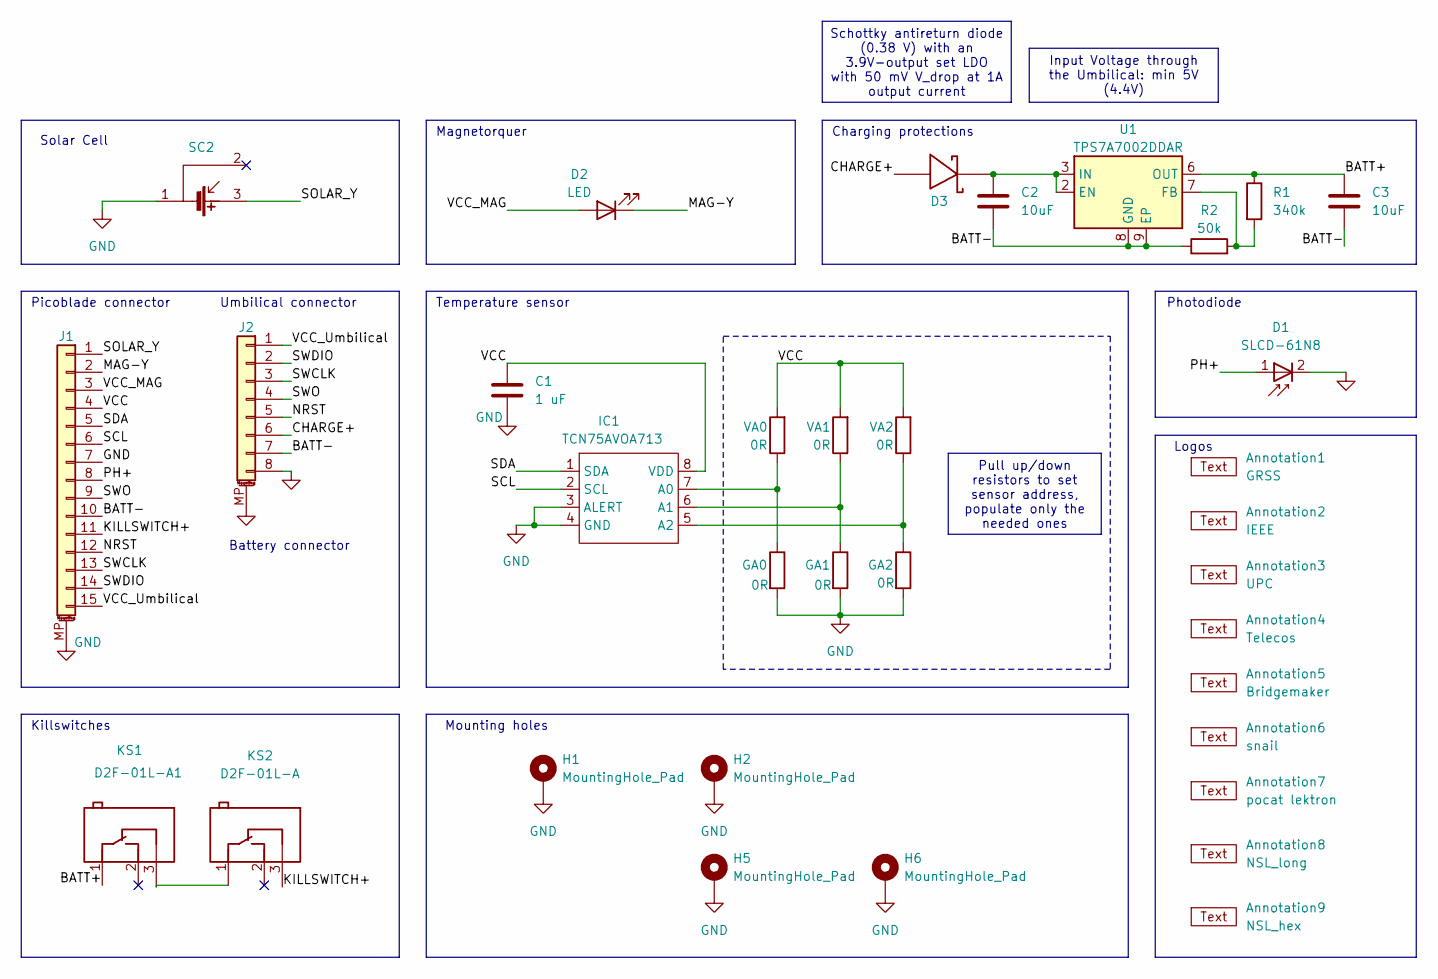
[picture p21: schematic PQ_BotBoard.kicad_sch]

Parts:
Annotation1: GRSS
Annotation2: IEEE; IEEE_logo
Annotation3: UPC; UPC_positiu
Annotation4: Telecos
Annotation5: Bridgemaker
Annotation6: snail; Snail
Annotation7: pocat lektron; pocat-lektron
Annotation8: NSL_long; NSL-small
Annotation9: NSL_hex; NSL_hexagon
C1: 1 uF; C_0603_1608Metric; Manufacturer Part Numbe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 GRM188R72A104KA35J
C2, C3: 10uF; C_0603_1608Metric
D1: SLCD-61N8; Manufacturer Part Numbe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 SLCD-61N8
D2: LED; LED_0402_1005Metric
D3: RBS1LAM40ATR_Schottky
GA0, GA1, GA2: 0R; R_0805_2012Metric; Manufacturer Part Numbe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 CRCW08055K00JNTA
H1, H2, H5, H6: MountingHole_Pad; MountingHole_2.2mm_M2_Pad; Manufacturer Part Numbe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 N/A
IC1: TCN75AVOA713; TCN75AVOA; Manufacturer Part Numbe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 TCN75AVOA
J1: 53261-1471; Molex_PicoBlade_53261-1571_1x15-1MP_P1.25mm_Horizontal; Manufacturer Part Numbe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 PicoBlade_53261-1571
J2: Conn_01x08_MountingPin; Molex_PicoBlade_53398-0871_1x08-1MP_P1.25mm_Vertical; Manufacturer Part Numbe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 PicoBlade_53398-0871
KS1: D2F-01L-A1; D2FLA1; Manufacturer Part Numbe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 D2F-01L
KS2: D2F-01L-A; D2FLA; Manufacturer Part Numbe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 D2F-01L-A
R1: 340k; R_0603_1608Metric
R2: 50k; R_0603_1608Metric
SC2: Lighttricity_S3040_CIC
U1: TPS7A7002DDAR; TI_SO-PowerPAD-8
VA0, VA1, VA2: 0R; R_0805_2012Metric; Manufacturer Part Numbe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 CRCW08055K00JNTA

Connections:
/BATT+: C3.1, KS1.1 (COM), R1.1, U1.6 (OUT)
/BATT-: C2.2, C3.2, J1.10, J2.7, R2.1, U1.8 (GND), U1.9 (EP)
/CHARGE+: D3.2, J2.6
/KILLSWITCH+: J1.11, KS2.3 (NC)
/MAG-Y: D2.1 (K), J1.2
/NRST: J1.12, J2.5
/PH+: D1.1, J1.8
/SCL: IC1.2 (SCL), J1.6
/SDA: IC1.1 (SDA), J1.5
/SOLAR_Y: J1.1, SC2.3
/SWCLK: J1.13, J2.3
/SWDIO: J1.14, J2.2
/SWO: J1.9, J2.4
/VCC: C1.1, IC1.8 (VDD), J1.4, VA0.2, VA1.2, VA2.2
/VCC_MAG: D2.2 (A), J1.3
/VCC_Umbilical: J1.15, J2.1
GND: C1.2, D1.2, GA0.2, GA1.2, GA2.2, H1.1, H2.1, H5.1, H6.1, IC1.3 (ALERT), IC1.4 (GND), J1.7, J1.MP (MountPin), J2.8, J2.MP (MountPin), SC2.1
unnamed: GA0.1, IC1.7 (A0), VA0.1
unnamed: GA1.1, IC1.6 (A1), VA1.1
unnamed: GA2.1, IC1.5 (A2), VA2.1
unnamed: KS1.3 (NC), KS2.1 (COM)
unnamed: C2.1, D3.1, U1.2 (EN), U1.3 (IN)
unnamed: R1.2, R2.2, U1.7 (FB)

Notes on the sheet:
Temperature sensor
Killswitches
Mounting holes
Solar Cell
Magnetorquer
Charging protections
Photodiode
Umbilical connector
Battery connector
Picoblade connector
Logos
Input Voltage through the Umbilical: min 5V (4.4V)
Schottky antireturn diode (0.38 V) with an 3.9V-output set LDO with 50 mV V_drop at 1A output current
Pull up/down resistors to set sensor address, populate only the needed ones

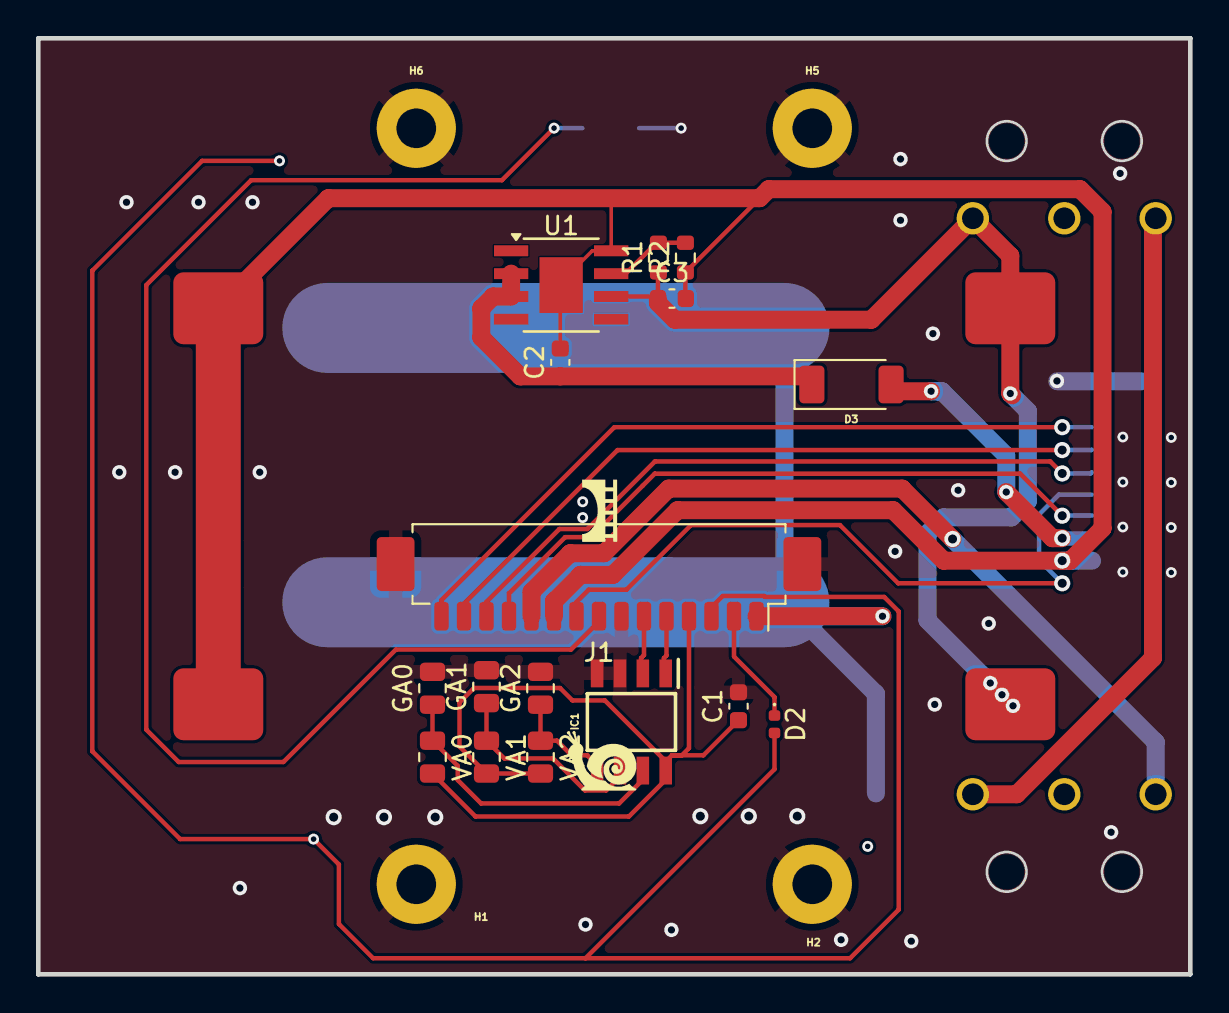
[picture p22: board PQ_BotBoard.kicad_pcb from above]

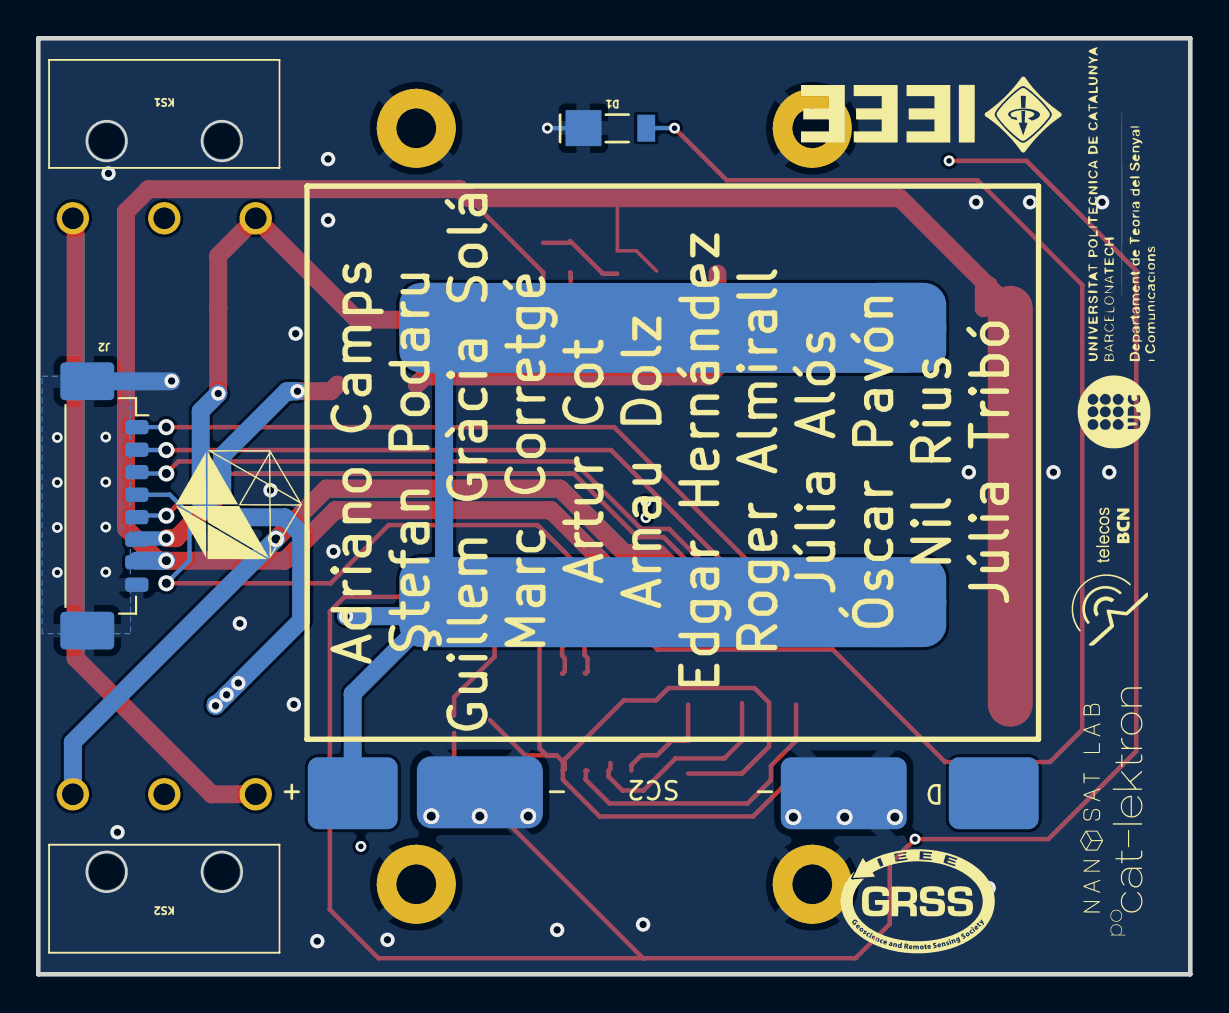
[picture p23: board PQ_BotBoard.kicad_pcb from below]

Board: 6 copper layers, 64.0 x 52.0 mm, 34 parts (12 on the bottom side), 23 nets.

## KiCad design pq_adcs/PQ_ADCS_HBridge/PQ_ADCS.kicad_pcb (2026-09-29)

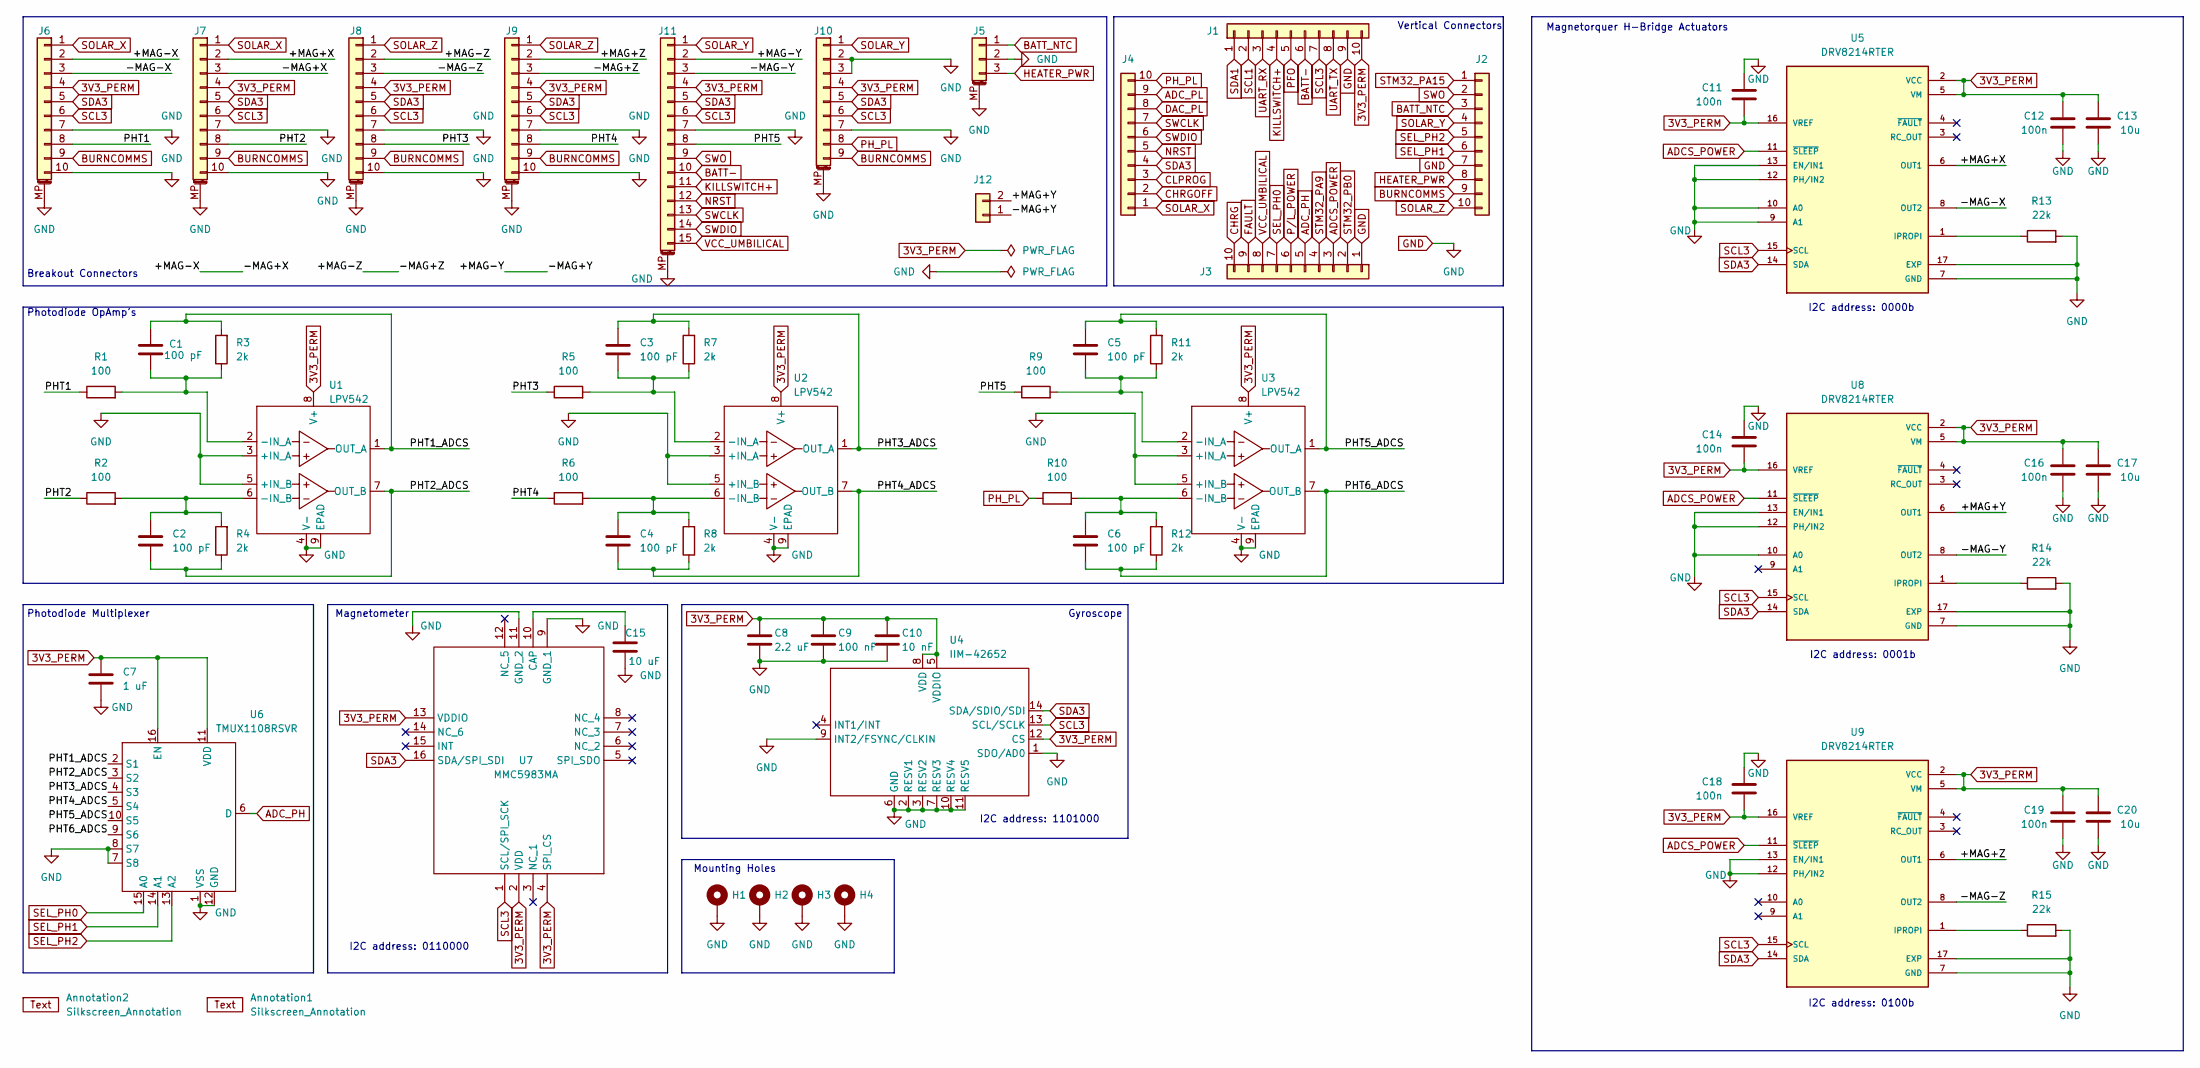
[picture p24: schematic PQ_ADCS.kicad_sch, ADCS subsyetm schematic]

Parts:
Annotation1: Silkscreen_Annotation; Bike
Annotation2: Silkscreen_Annotation; Bridgemaker
C1, C2, C3, C4, C5, C6: 100 pF; C_0603_1608Metric; Manufacturer Part Numbe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 06035C101K4T2A
C7: 1 uF; C_0603_1608Metric; Manufacturer Part Numbe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 GRM188R61A105KA61D
C8: 2.2 uF; C_0603_1608Metric; Manufacturer Part Numbe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 GRM033R60J225ME15D
C9: 100 nF; C_0603_1608Metric; Manufacturer Part Numbe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 GRM188R72A104KA35J
C10: 10 nF; C_0603_1608Metric; Manufacturer Part Numbe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 0201YD103KAT4A
C11, C12, C14, C16, C18, C19: 100n; C_0603_1608Metric
C13, C17, C20: 10u; C_0603_1608Metric
C15: 10 uF; C_0805_2012Metric; Manufacturer Part Numbe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 GRM188R72A104KA35J
H1, H2, H3, H4: MountingHole_Pad; MountingHole_3.2mm_M3_Pad; Manufacturer Part Numbe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 N/A
J1, J2, J3, J4: CES-110-02-L-S; SLW-110-01; Manufacturer Part Numbe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 CES-110-02-L-S
J5: Pico-Clasp_01x03; Picoclasp03; Manufacturer Part Numbe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 203556-0307
J6, J7, J8, J9: Pico-Clasp_01x10; Picoclasp10; Manufacturer Part Numbe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 504449-1007
J10: Pico-Clasp_01x09; Picoclasp09; Manufacturer Part Numbe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 504449-0907
J11: Pico-Clasp_01x15; Picoclasp15; Manufacturer Part Numbe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 504449-1507
J12: CES-102-02-L-S; CES-102-02; Manufacturer Part Numbe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 CES-102-02-L-S
R1, R2, R5, R6, R9, R10: 100; R_0603_1608Metric; Manufacturer Part Numbe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 AC0603FR-13100RL
R3, R4, R7, R8, R11, R12: 2k; R_0603_1608Metric; Manufacturer Part Numbe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 RC0603FR-132KL
R13, R14, R15: 22k; R_0603_1608Metric; Manufacturer Part Numbe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 AC0603FR-13100RL
U1, U2, U3: LPV542; TI_X1SON-8_3x3mm; Manufacturer Part Numbe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 LPV542DNXR
U4: IIM-42652; IIM42652; Manufacturer_Part_Number IIM-42652; Mouser Part Number 410-IIM-42652
U5, U8, U9: DRV8214RTER; IC_DRV8214RTER; PARTREV November 2023
U6: TMUX1108RSVR; UQFN-16_1.8x2.6_Pitch0.4mm; Manufacturer Part Numbe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 TMUX1108RSVR
U7: MMC5983MA; Manufacturer_Part_Number MMC5983MA; Mouser Part Number 438-MMC5983MA

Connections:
3V3_PERM: C7.1, C8.1, C9.1, C10.1, C11.2, C12.1, C13.1, C14.2, C16.1, C17.1, C18.2, C19.1, C20.1, J1.10, J6.4, J7.4, J8.4, J9.4, J10.4, J11.4, U1.8 (V+), U2.8 (V+), U3.8 (V+), U4.5 (VDDIO), U4.8 (VDD), U4.12 (CS), U5.2 (VCC), U5.5 (VM), U5.16 (VREF), U6.11 (VDD), U6.16 (EN), U7.2 (VDD), U7.4 (SPI_CS), U7.13 (VDDIO), U8.2 (VCC), U8.5 (VM), U8.16 (VREF), U9.2 (VCC), U9.5 (VM), U9.16 (VREF)
/+MAG+X: J7.2, U5.6 (OUT1)
/+MAG+Y: J12.2, U8.6 (OUT1)
/+MAG+Z: J9.2, U9.6 (OUT1)
/+MAG-X: J6.2, J7.3
/+MAG-Y: J11.2, J12.1
/+MAG-Z: J8.2, J9.3
/-MAG-X: J6.3, U5.8 (OUT2)
/-MAG-Y: J11.3, U8.8 (OUT2)
/-MAG-Z: J8.3, U9.8 (OUT2)
/PHT1: J6.8, R1.1
/PHT1_ADCS: C1.1, R3.2, U1.1 (OUT_A), U6.2 (S1)
/PHT2: J7.8, R2.1
/PHT2_ADCS: C2.2, R4.1, U1.7 (OUT_B), U6.3 (S2)
/PHT3: J8.8, R5.1
/PHT3_ADCS: C3.1, R7.2, U2.1 (OUT_A), U6.4 (S3)
/PHT4: J9.8, R6.1
/PHT4_ADCS: C4.2, R8.1, U2.7 (OUT_B), U6.5 (S4)
/PHT5: J11.8, R9.1
/PHT5_ADCS: C5.1, R11.2, U3.1 (OUT_A), U6.10 (S5)
/PHT6_ADCS: C6.2, R12.1, U3.7 (OUT_B), U6.9 (S6)
ADCS_POWER: J3.3, U5.11 (~SLEEP), U8.11 (~SLEEP), U9.11 (~SLEEP)
ADC_PH: J3.5, U6.6 (D)
ADC_PL: J4.9
BATT-: J1.6, J11.10
BATT_NTC: J2.3, J5.1
BURNCOMMS: J2.9, J6.9, J7.9, J8.9, J9.9, J10.9
CHRG: J3.10
CHRGOFF: J4.2
CLPROG: J4.3
DAC_PL: J4.8
FAULT: J3.9
GND: C7.2, C8.2, C9.2, C10.2, C11.1, C12.2, C13.2, C14.1, C15.2, C16.2, C17.2, C18.1, C19.2, C20.2, H1.1, H2.1, H3.1, H4.1, J1.9, J2.7, J3.1, J5.2, J5.MP, J6.7, J6.10, J6.MP, J7.7, J7.10, J7.MP, J8.7, J8.10, J8.MP, J9.7, J9.10, J9.MP, J10.2, J10.3, J10.7, J10.MP, J11.7, J11.MP, R13.2, R14.2, R15.2, U1.3 (+IN_A), U1.4 (V-), U1.5 (+IN_B), U1.9 (EPAD), U2.3 (+IN_A), U2.4 (V-), U2.5 (+IN_B), U2.9 (EPAD), U3.3 (+IN_A), U3.4 (V-), U3.5 (+IN_B), U3.9 (EPAD), U4.1 (SDO/AD0), U4.2 (RESV1), U4.3 (RESV2), U4.6 (GND), U4.7 (RESV3), U4.9 (INT2/FSYNC/CLKIN), U4.10 (RESV4), U4.11 (RESV5), U5.7 (GND), U5.9 (A1), U5.10 (A0), U5.12 (PH/IN2), U5.13 (EN/IN1), U5.17 (EXP), U6.1 (VSS), U6.7 (S8), U6.8 (S7), U6.12 (GND), U7.9 (GND_1), U7.11 (GND_2), U8.7 (GND), U8.10 (A0), U8.12 (PH/IN2), U8.13 (EN/IN1), U8.17 (EXP), U9.7 (GND), U9.12 (PH/IN2), U9.13 (EN/IN1), U9.17 (EXP)
HEATER_PWR: J2.8, J5.3
KILLSWITCH+: J1.4, J11.11
NRST: J4.5, J11.12
unnamed: C1.2, R1.2, R3.1, U1.2 (-IN_A)
unnamed: C2.1, R2.2, R4.2, U1.6 (-IN_B)
unnamed: C3.2, R5.2, R7.1, U2.2 (-IN_A)
unnamed: C4.1, R6.2, R8.2, U2.6 (-IN_B)
unnamed: C5.2, R9.2, R11.1, U3.2 (-IN_A)
unnamed: C6.1, R10.2, R12.2, U3.6 (-IN_B)
unnamed: R13.1, U5.1 (IPROPI)
unnamed: C15.1, U7.10 (CAP)
unnamed: R14.1, U8.1 (IPROPI)
unnamed: R15.1, U9.1 (IPROPI)
PFO: J1.5
PH_PL: J4.10, J10.8, R10.1
P/L_POWER: J3.6
SCL1: J1.2
SCL3: J1.7, J6.6, J7.6, J8.6, J9.6, J10.6, J11.6, U4.13 (SCL/SCLK), U5.15 (SCL), U7.1 (SCL/SPI_SCK), U8.15 (SCL), U9.15 (SCL)
SDA1: J1.1
SDA3: J4.4, J6.5, J7.5, J8.5, J9.5, J10.5, J11.5, U4.14 (SDA/SDIO/SDI), U5.14 (SDA), U7.16 (SDA/SPI_SDI), U8.14 (SDA), U9.14 (SDA)
SEL_PH0: J3.7, U6.15 (A0)
SEL_PH1: J2.6, U6.14 (A1)
SEL_PH2: J2.5, U6.13 (A2)
SOLAR_X: J4.1, J6.1, J7.1
SOLAR_Y: J2.4, J10.1, J11.1
SOLAR_Z: J2.10, J8.1, J9.1
STM32_PA9: J3.4
STM32_PA15: J2.1
STM32_PB0: J3.2
SWCLK: J4.7, J11.13
SWDIO: J4.6, J11.14
SWO: J2.2, J11.9
UART_RX: J1.3
UART_TX: J1.8
VCC_UMBILICAL: J3.8, J11.15

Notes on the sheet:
I2C address: 0100b
Mounting Holes
Breakout Connectors
I2C address: 1101000
Photodiode Multiplexer
Gyroscope
I2C address: 0000b
I2C address: 0110000
I2C address: 0001b
Photodiode OpAmp's
Magnetorquer H-Bridge Actuators
Vertical Connectors
Magnetometer

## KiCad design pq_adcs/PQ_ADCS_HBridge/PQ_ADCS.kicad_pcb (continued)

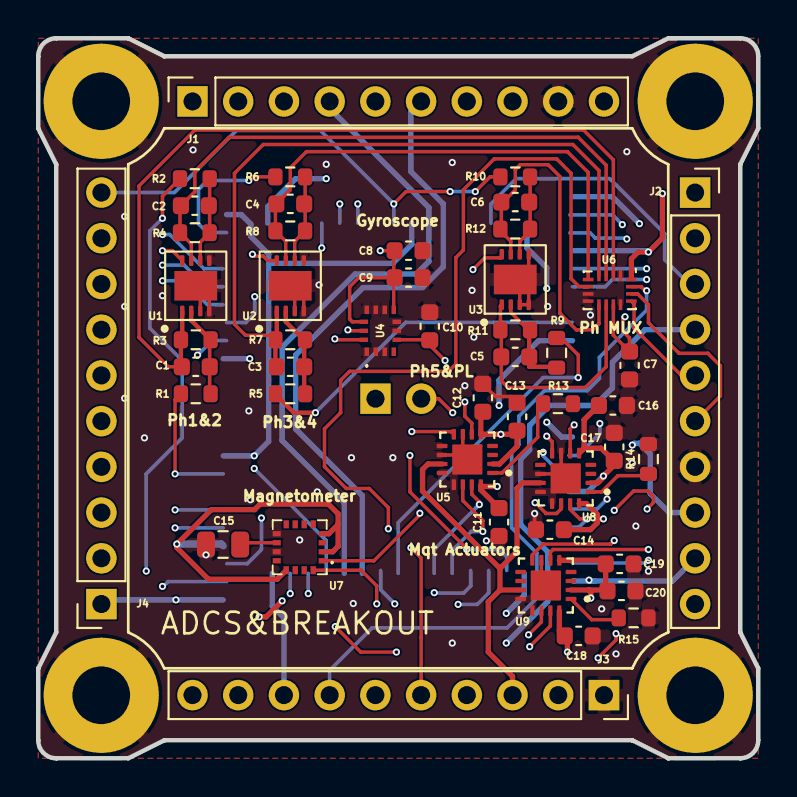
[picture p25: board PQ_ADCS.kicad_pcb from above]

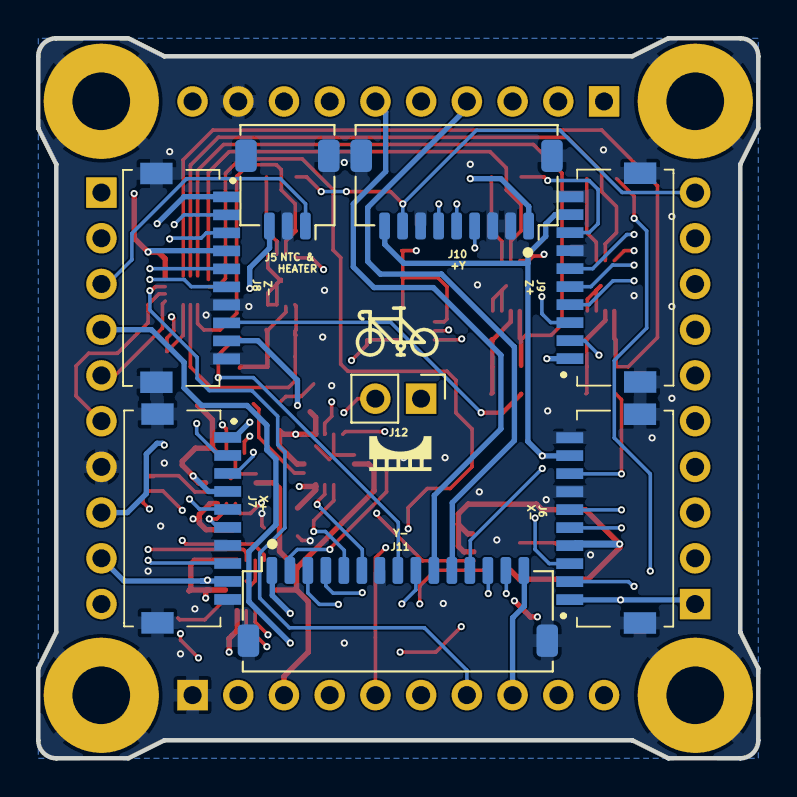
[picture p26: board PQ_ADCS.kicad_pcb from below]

Board: 6 copper layers, 40.0 x 40.0 mm, 62 parts (10 on the bottom side), 53 nets.

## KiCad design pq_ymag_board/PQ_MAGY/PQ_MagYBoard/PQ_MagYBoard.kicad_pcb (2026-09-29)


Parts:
Annotation1: Bridgemaker
Annotation2: NSL_hexagon
Annotation3: snail; Snail
Annotation4: snail; pocat_lektron
D1: LED; LED_0402_1005Metric
H1, H2, H3, H4: MountingHole; MountingHole_6.4mm_M6_DIN965
H5, H6, H7, H8: MountingHole; MountingHole_2.2mm_M2_DIN965
J1: M20-7810245; M207810245; Manufacturer_Part_Number M20-7810245; Mouser Part Number 855-M20-7810245

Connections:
/MAG+Y: D1.1 (K), J1.2, J1.4
/VCC_MAG: D1.2 (A), J1.1, J1.3

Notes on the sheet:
Logos
Mounting Holes
ADCS magnetorquer netie
Central Vertical Connector


Board: 6 copper layers, 45.0 x 45.0 mm, 14 parts (1 on the bottom side), 2 nets.

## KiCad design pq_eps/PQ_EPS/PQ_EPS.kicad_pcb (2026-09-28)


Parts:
Annotation1: Silkscreen_Annotation; Bridgemaker
Annotation2: Silkscreen_Annotation; NakNak
Annotation3: Silkscreen_Annotation; Snail
C1: 2.2u; C_0603_1608Metric; Manufacturer Part Numbe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 GRM155R61C225KE11D
C2: 10u; C_0603_1608Metric; Manufacturer Part Numbe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 GRM188R61A106KAALD
C3: 100u; C_1206_3216Metric; Manufacturer Part Numbe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 GRM21BR60J107ME15K
C4: 0.1u; C_0603_1608Metric; Manufacturer Part Numbe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 C0603C104K8PACTU
C5: 22u; C_0603_1608Metric; Manufacturer Part Numbe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 GRM187R61A226ME15J
CF1, CF2, CF3: 1u; C_0603_1608Metric; Manufacturer Part Numbe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 GRM155R61C105KA12D
CIN1, CIN2, CIN3: 1.5u; C_0603_1608Metric; Manufacturer Part Numbe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 C1005X5R1V155K050BC
CINSNS1, CINSNS2, CINSNS3: 1n; C_0603_1608Metric; Manufacturer Part Numbe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 GRM155R61A102KA01D
COUT1, COUT2, COUT3: 10u; C_0603_1608Metric; Manufacturer Part Numbe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 GRM188R61A106KAALD
COUTSNS1, COUTSNS2, COUTSNS3: 1n; C_0603_1608Metric; Manufacturer Part Numbe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 GRM155R61A102KA01D
D1, D2, D3: SMM4F; SMM4F15ATR; Manufacturer Part Numbe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 SMM4F18A-TR
D4, D5, D6: shottky; RBS1LAM40ATR_Schottky; Manufacturer Part Numbe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 RBS1LAM40ATR
DNC1, DNC2: 20k; R_0603_1608Metric; Manufacturer Part Numbe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 ERJ-UP3J203V
H1, H2, H3, H4: MountingHole_Pad; MountingHole_3.2mm_M3_Pad; Manufacturer Part Numbe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 N/A
IC1: DS2782E+; TSSOP-8_4.4x3mm_P0.65mm; Manufacturer Part Numbe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 DS2782E+
IC2: ISL9120IRTNZ; Manufacturer Part Numbe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 ISL9120IRTNZ
J1, J2, J3, J4: CES-110-02-L-S; SLW-110-01; Manufacturer Part Numbe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 CES-110-02-L-S
J5: CES-102-02
L1, L2, L3: 10u; L_0805_2012Metric; Manufacturer Part Numbe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 LQH2MPZ100MGRL
L4: 2.2u; XAL5030222MEC; Manufacturer_Part_Number XAL5030-222MEC; Mouser Part Number 994-XAL5030-222MEC
L5: 1u; L_0805_2012Metric; Manufacturer Part Numbe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 TFM201610GHM1R0A
Q1: SIR424DP; Manufacturer Part Numbe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 SIR424DP-T1-GE3
R1, R2, R3, R8: 1k; R_0603_1608Metric
R4: 75m; R_0805_2012Metric; Manufacturer Part Numbe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 UR73V2ATTD75L0F
R5: 10M; R_0805_2012Metric; Manufacturer Part Numbe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 UR73V2ATTD75L0F
R6: 2k; R_0603_1608Metric
R7: 510; R_0603_1608Metric
R9: 15m; R_0603_1608Metric
RBIAS1: 10k; R_0603_1608Metric
RF1, RF2, RF3, RF4, RF5, RF6: 1k; R_0603_1608Metric; Manufacturer Part Numbe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 CRCW04021K00FKEDHP
RFB1: 68k; R_0603_1608Metric; Manufacturer Part Numbe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 SG73P1ETTP6802F
RFB2: 255k; R_0402_1005Metric; Manufacturer Part Numbe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 ERJ-U02F2553X
RFG0, RFG1, RFG2: 1k; R_0603_1608Metric; Manufacturer Part Numbe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 PCAN0805E1001BST5
RFV0, RFV1, RFV2: 1k; R_0603_1608Metric; Manufacturer Part Numbe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 PCAN0805E1001BST5
RH1, RH2, RH3: 910k; R_0603_1608Metric; Manufacturer Part Numbe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 ERJ-PA3F9103V
RL1, RL2, RL3: 360k; R_0603_1608Metric; Manufacturer Part Numbe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 ERJ-UP3F3603V
RPF1: 147k; R_0603_1608Metric; Manufacturer Part Numbe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 ERJ-P03F1473V
RPF2: 68k; R_0603_1608Metric; Manufacturer Part Numbe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 SG73P1ETTP6802F
RP_CHRG1: 5k; R_0805_2012Metric; Manufacturer Part Numbe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 CRCW08055K00JNTA
RP_FAULT1: 5k; R_0805_2012Metric; Manufacturer Part Numbe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 CRCW08055K00JNTA
RS1, RS2, RS3: 300m; R_0603_1608Metric; Manufacturer Part Numbe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 UCR03EVPFLR300
U1, U2, U3: SPV1040TTR; TSSOP-8_4.4x3mm_P0.65mm; Manufacturer Part Numbe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 SPV1040TTR
U4: LTC4040EUFD#PBF; QFN-24-1EP_4x5mm_P0.5mm_EP2.65x3.65mm; Manufacturer Part Numbe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 LTC4040IUFD#PBF

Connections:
3V3_PERM: C5.2, IC2.10 (FB), IC2.11 (VOUT), J1.10, RBIAS1.2
ADCS_POWER: J3.3
ADC_PH: J3.5
ADC_PL: J4.9
BATT-: C4.2, IC1.2 (VSS), J1.6, R9.1
BATT_NTC: J2.3, RBIAS1.1, U4.17 (NTC)
BURNCOMMS: J2.9
CHOUT: C3.1, IC2.5 (VIN_1), IC2.6 (VIN_2), Q1.5 (D), RFB2.2, RFV0.1, RFV1.1, RFV2.1, RP_CHRG1.1, RP_FAULT1.1, U4.1 (VSYS), U4.24 (VSYS)
CHRG: J3.10, RP_CHRG1.2, U4.8 (CHRG#)
CHRGOFF: J4.2, U4.4 (CHGOFF)
CLPROG: J4.3, U4.3 (CLPROG)
DAC_PL: J4.8
F0: RFG0.1, RFV0.2, U4.14 (F0)
F1: RFG1.1, RFV1.2, U4.13 (F1)
F2: RFG2.1, RFV2.2, U4.12 (F2)
FAULT: J3.9, RP_FAULT1.2, U4.9 (FAULT#)
GND: C1.2, C2.2, C3.2, C5.1, CIN1.1, CIN2.1, CIN3.1, CINSNS1.1, CINSNS2.1, CINSNS3.1, COUT1.1, COUT2.1, COUT3.1, COUTSNS1.1, COUTSNS2.1, COUTSNS3.1, D1.2, D2.2, D3.2, H1.1, H2.1, H3.1, H4.1, IC1.7 (SNS), IC2.2 (PGND), IC2.7 (BYPS), IC2.8 (GND), IC2.13 (EP), J1.9, J2.7, J3.1, J5.1, R5.2, R6.1, R9.2, RFB1.2, RFG0.2, RFG1.2, RFG2.2, RL1.2, RL2.2, RL3.2, RPF2.1, U1.2 (GND), U2.2 (GND), U3.2 (GND), U4.5 (BSTOFF), U4.25 (EPAD)
HEATER_PWR: J2.8
KILLSWITCH+: C2.1, DNC1.2, DNC2.2, IC2.9 (EN), J1.4, L4.2, R5.1, R7.2, R8.2, U4.23 (BAT)
NRST: J4.5, U4.11 (RST#)
unnamed: D1.1, D4.2, RF2.2, RH1.1, RS1.2
unnamed: D2.1, D5.2, RF3.2, RH2.1, RS2.2
unnamed: D3.1, D6.2, RF5.2, RH3.1, RS3.2
unnamed: C4.1, IC1.4 (VDD), R7.1
unnamed: IC1.3 (VIN), R8.1
unnamed: IC2.3 (LX1_1), IC2.4 (LX1_2), L5.1
unnamed: IC2.1 (LX2_1), IC2.12 (LX2_2), L5.2
unnamed: L4.1, U4.21 (SW), U4.22 (SW)
unnamed: Q1.4 (G), U4.15 (IGATE)
unnamed: CF1.1, RF2.1, U1.6 (ICTRL-MINUS)
unnamed: CF1.2, RF1.1, U1.7 (ICTRL-PLUS)
unnamed: L1.1, U1.3 (LX)
unnamed: CINSNS1.2, R1.1, U1.1 (MPP-SET), U1.8 (XSHUT)
unnamed: COUTSNS1.2, RH1.2, RL1.1, U1.5 (VCTRL)
unnamed: COUT1.2, RF1.2, RS1.1, U1.4 (VOUT)
unnamed: CF2.1, RF3.1, U2.6 (ICTRL-MINUS)
unnamed: CF2.2, RF4.1, U2.7 (ICTRL-PLUS)
unnamed: L2.2, U2.3 (LX)
unnamed: CINSNS2.2, R2.1, U2.1 (MPP-SET), U2.8 (XSHUT)
unnamed: COUTSNS2.2, RH2.2, RL2.1, U2.5 (VCTRL)
unnamed: COUT2.2, RF4.2, RS2.1, U2.4 (VOUT)
unnamed: CF3.1, RF5.1, U3.6 (ICTRL-MINUS)
unnamed: CF3.2, RF6.1, U3.7 (ICTRL-PLUS)
unnamed: L3.2, U3.3 (LX)
unnamed: CINSNS3.2, R3.1, U3.1 (MPP-SET), U3.8 (XSHUT)
unnamed: COUTSNS3.2, RH3.2, RL3.1, U3.5 (VCTRL)
unnamed: COUT3.2, RF6.2, RS3.1, U3.4 (VOUT)
unnamed: RFB1.1, RFB2.1, U4.10 (RSTFB), U4.18 (BSTFB)
unnamed: Q1.1 (S), Q1.2 (S), Q1.3 (S), R4.2, U4.7 (CLN)
unnamed: RPF1.1, RPF2.2, U4.19 (PFI)
OVSNS: C1.1, D4.1, D5.1, D6.1, J5.2, R4.1, RPF1.2, U4.6 (VIN), U4.16 (OVSNS)
PFO: J1.5, U4.20 (PF0#)
PH_PL: J4.10
PROG: R6.2, U4.2 (PROG)
P/L_POWER: J3.6
SCL1: DNC1.1, IC1.6 (SCL), J1.2
SCL3: J1.7
SDA1: DNC2.1, IC1.5 (SDA), J1.1
SDA3: J4.4
SEL_PH0: J3.7
SEL_PH1: J2.6
SEL_PH2: J2.5
SOLAR_X: CIN1.2, J4.1, L1.2, R1.2
SOLAR_Y: CIN2.2, J2.4, L2.1, R2.2
SOLAR_Z: CIN3.2, J2.10, L3.1, R3.2
STM32_PA9: J3.4
STM32_PA15: J2.1
STM32_PB0: J3.2
SWCLK: J4.7
SWDIO: J4.6
SWO: J2.2
UART_RX: J1.3
UART_TX: J1.8
VCC_UMBILICAL: J3.8

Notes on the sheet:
ENERGY HARVEST BLOCK
Vertical connectors
MOUNTING HOLES
VOLTAGE REGULATOR
CHARGE / DISCHARGE IC
BATTERY SENSOR
April 1st 2022
1.11



Board: 4 copper layers, 40.0 x 40.0 mm, 89 parts (47 on the bottom side), 52 nets.

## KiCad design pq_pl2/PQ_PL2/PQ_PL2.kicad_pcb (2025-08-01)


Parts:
Annotation1: Silkscreen_Annotation; Bridgemaker; Manufacturer Part Numbe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 N/A
Annotation2: Silkscreen_Annotation; GRSS; Manufacturer Part Numbe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 N/A
Annotation3: Silkscreen_Annotation; NSL_long; Manufacturer Part Numbe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 N/A
Annotation4: Silkscreen_Annotation; IEEE_logo; Manufacturer Part Numbe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 N/A
Annotation5: Silkscreen_Annotation; UPC_positiu; Manufacturer Part Numbe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 N/A
C1, C2, C3, C4, C32: 1nF; C_0603_1608Metric; Manufacturer Part Numbe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 885382206005
C5, C6, C9, C10, C14, C34: 47nF; C_0603_1608Metric; Manufacturer Part Numbe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 CGA3E3X7S2A473K080AE
C7, C8: 47nF; C_0402_1005Metric; Manufacturer Part Numbe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 MAASU105SB7473KFCA01
C11: 2.2pF; C_0603_1608Metric; Manufacturer Part Numbe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 06031U2R2CAT2A
C12: 270pF; C_0603_1608Metric; Manufacturer Part Numbe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 06031A271FAT2A
C13: 22pF; C_0603_1608Metric; Manufacturer Part Numbe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 CBR06C220J5GACAUTO
C15, C16: 1.2nF; C_0603_1608Metric; Manufacturer Part Numbe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 C0603C122F1GACTU
C17, C23: 300pF; C_0402_1005Metric; Manufacturer Part Numbe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 GRT1555C1H301FA02D
C18, C19, C21, C22: 1.3pF; C_0402_1005Metric; Manufacturer Part Numbe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 CBR04C139A5GAC
C20: 500pF; C_0402_1005Metric; Manufacturer Part Numbe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 0402ZC501KAT2A
C24, C25: 12 pF; C_0402_1005Metric; Manufacturer Part Numbe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 CBR04C120F2GAC
C26, C27: 10nF; C_0402_1005Metric; Manufacturer Part Numbe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 GRM1555C1E103GE01D
C28: 27pF; C_0603_1608Metric; Manufacturer Part Numbe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 CBR04C270F2GAC
C29: 33nF; C_0603_1608Metric; Manufacturer Part Numbe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 0402YC333JAT2A
C30, C33: 1uF; C_0603_1608Metric; Manufacturer Part Numbe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 MAASA105CD7105KFCA01
C31: 4.7uF; C_0603_1608Metric; Manufacturer Part Numbe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 C1005X5R1A475K050BC
D1: SLCD-61N8; Manufacturer Part Numbe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 SLCD-61N8
FL1: BFCG162W; GE0805C-3; Manufacturer Part Numbe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 BFCG-162W+
H1, H2, H3, H4: MountingHole_Pad; MountingHole_3.2mm_M3_Pad; Manufacturer Part Numbe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 N/A
J1, J2, J3, J4: BBL-110-Y-X; Manufacturer Part Numbe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 BBL-110-Y-X
J5, J8: U.FL-R-SMT; U.FL-R-SMT-1(10); Manufacturer Part Numbe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 U.FL-R-SMT-1(10); JLCPCB PART CLASS Extended Part
J6, J7: MS-156C3; CoaxialSwitch_Hirose_MS-156C3_Horizontal; Manufacturer Part Numbe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 MS-156C3
L1: 100nH; L_0603_1608Metric; Manufacturer Part Numbe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 7447860210G
L2, L8: 16.4nH; L_0402_1005Metric; Manufacturer Part Numbe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 LQG15WZ16NG02D
L3, L4, L6, L7: 3.9nH; L_0402_1005Metric; Manufacturer Part Numbe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 LQW15AN3N9G80D
L5: 10.2nH; L_0402_1005Metric; Manufacturer Part Numbe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 LQG15WZ10NG02D
L9: 680 nH; L_0402_1005Metric; Manufacturer Part Numbe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 MLF1005GR68KT000
L10: 4.7uH; L_0603_1608Metric; Manufacturer Part Numbe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 MLF1608A3R3JTD25
R1: 87.5; R_0603_1608Metric; Manufacturer Part Numbe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 ERA-3AEB86R6V
R2, R3: 75; R_0603_1608Metric; Manufacturer Part Numbe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 TNPU060375R0BZEN0
R4: 120k; R_0603_1608Metric; Manufacturer Part Numbe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 TNPW0603120KBYEN
R5: 15k; R_0603_1608Metric; Manufacturer Part Numbe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 RP0603BRD0715KL
R6, R7: 33K; R_0603_1608Metric; Manufacturer Part Numbe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 RP0603BRD0733KL
R10: 360k; R_0603_1608Metric; Manufacturer Part Numbe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 RP0603BRD072KL
R11: 120k; R_0603_1608Metric; Manufacturer Part Numbe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 RP0603BRD072KL
U1: LEE2-6+; WSON-6-1EP_2x2mm_P0.65mm_EP1x1.6mm; Manufacturer Part Numbe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 LEE2-6+
U2: MAX2121; QFN50P500X500X80-29N; Manufacturer Part Numbe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 MAX2121
U3: LT5537; SON50P200X300X80-9N-D; Manufacturer Part Numbe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 LT5537
U4: LT3048; SON45P200X200X80-9N; Manufacturer Part Numbe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 LT3048
Y1: ECS-TXO-2016MV; ECSTXO201633320TR; Manufacturer Part Numbe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 ECS-TXO-2016MV

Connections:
3V3_PERM: J1.10
5V: C33.2, R1.1, R10.2, U4.6 (LDOUT)
A+: C18.1, L3.2
A-: C19.1, L4.2
ADCS_POWER: J3.3
ADC_PH: J3.5
ADC_PL: C28.1, J4.9, R7.2
B+: C20.2, C21.2, L3.1, L5.1
B-: C20.1, C22.2, L4.1, L5.2
BATT-: J1.6
BATT_NTC: J2.3
BURNCOMMS: J2.9
C+: C21.1, L6.2
C-: C22.1, L7.2
CHGOFF: J4.2
CHRG: J3.10
CLPROG: J4.3
D+: C24.1, C26.2, L9.2
D-: C25.1, C27.2, L9.1
DAC_PL: J4.8, U2.5 (GC1)
E+: C26.1, U3.2 (IN+)
E-: C27.1, U3.3 (IN-)
FAULT: J3.9
GND: C4.2, C11.2, C13.2, C14.2, C28.2, C30.2, C31.1, C32.1, C33.1, C34.1, D1.2, FL1.2 (GND), FL1.4 (GND), H1.1, H2.1, H3.1, H4.1, J1.9, J2.7, J2.10, J5.2, J6.G, J7.G, J8.2, R2.2, R3.2, R5.2, R6.1, R11.1, U1.1 (NC), U1.3 (NC), U1.4 (NC), U1.6 (NC), U1.7 (GND), U2.3 (GND), U2.10 (GNDTUNE), U2.11 (GNDSYN), U2.28 (ADDR), U2.29 (EP), U3.7 (VEE), U3.9 (EPAD), U4.3 (GND1), U4.9 (GND2), Y1.2 (GND); also elsewhere on the board
HEATER_PWR: J2.8
IF+: C8.1, C17.2, C18.2, L2.1
IF-: C7.1, C17.1, C19.2, L2.2
IO+: C8.2, U2.19 (IOUT+)
IO-: C7.2, U2.20 (IOUT-)
KILLSWITCH+: J1.4
NRST: J4.5
unnamed: C1.1, J5.1
unnamed: C2.2, J6.I
unnamed: C9.1, R2.1
unnamed: C10.1, R3.1
unnamed: C12.2, R5.1
unnamed: C16.2, J8.1
unnamed: FL1.1 (IN), J6.O
unnamed: C3.1, FL1.3 (Out)
unnamed: L1.1, R1.2
unnamed: C1.2, U1.2 (In)
unnamed: C2.1, L1.2, U1.5 (Out&DCin)
unnamed: C14.1, U2.8 (BYPVCO)
unnamed: C12.1, C13.1, R4.2, U2.12 (CPOUT)
unnamed: C6.1, U2.21 (IDC+)
unnamed: C6.2, U2.22 (IDC-)
unnamed: C5.1, U2.23 (QDC+)
unnamed: C5.2, U2.24 (QDC-)
unnamed: C10.2, U2.17 (QOUT+)
unnamed: C9.2, U2.18 (QOUT-)
unnamed: C16.1, U2.15 (REFOUT)
unnamed: J7.O, U2.4 (RFIN)
unnamed: C11.1, R4.1, U2.9 (TUNEVCO)
unnamed: C15.1, U2.14 (XTAL)
unnamed: C29.2, U3.4 (CAP+)
unnamed: C29.1, U3.5 (CAP-)
unnamed: R6.2, R7.1, U3.8 (OUT)
unnamed: C31.2, U4.8 (BSTOUT)
unnamed: C32.2, U4.4 (BYP)
unnamed: R10.1, R11.2, U4.5 (FB)
unnamed: L10.2, U4.1 (SW)
unnamed: C15.2, Y1.3 (Out)
PFO: J1.5
PH_PL: D1.1, J4.10
P/L_POWER: C4.1, C30.1, C34.2, J3.6, L10.1, U2.1 (VCC_RF1), U2.2 (VCC_RF2), U2.6 (VCC_LO), U2.7 (VCC_VCO), U2.13 (VCC_SYN), U2.16 (VCC_DIG), U2.25 (VCC_BB), U3.1 (ENBL), U3.6 (VCC), U4.2 (VIN), U4.7 (EN), Y1.1 (Tri), Y1.4 (VDD); also elsewhere on the board
RF: C3.2, J7.I
RSSI+: C23.2, C25.2, L6.1, L8.1
RSSI-: C23.1, C24.2, L7.1, L8.2
RST_DRIVERS: J3.4
SCL1: J1.2, U2.27 (SCL)
SCL3: J1.7
SDA1: J1.1, U2.26 (SDA)
SDA3: J4.4
SEL_PH0: J3.7
SEL_PH1: J2.6
SEL_PH2: J2.5
SOLAR_X: J4.1
SOLAR_Y: J2.4
SOLAR_Z: J3.1
STM32_PA15: J2.1
STM32_PB0: J3.2; also elsewhere on the board
SWCLK: J4.7
SWDIO: J4.6
SWO: J2.2
UART_RX: J1.3
UART_TX: J1.8
VCC_UMBILICAL: J3.8

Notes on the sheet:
add stowing &deployment mechanism
VERTICAL CONNECTORS
MOUNTING HOLES
IF CHAIN
5 V BOOSTER
RF CHAIN
TUNER
RSSI
ANNOTATIONS
PHOTODIODE



Board: 4 copper layers, 40.0 x 40.0 mm, 81 parts (67 on the bottom side), 59 nets.

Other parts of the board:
C35: 100 pF; C_0603_1608Metric
R8: 100; R_0603_1608Metric
R9: 2k; R_0603_1608Metric
U5: TL071; TSOT-23-5

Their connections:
GND: U5.3 (+), U5.5 (V+); also elsewhere on the board
unnamed: C35.2, R8.2, R9.1
unnamed: R8.1, U5.4 (-)
P/L_POWER: U5.2 (V-); also elsewhere on the board
STM32_PB0: C35.1, R9.2, U5.1; also elsewhere on the board

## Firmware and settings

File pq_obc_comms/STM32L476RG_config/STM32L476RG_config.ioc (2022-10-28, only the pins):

Mcu.UserName=STM32L476RGTx
PA1.Signal=ADCx_IN6
PA10.Signal=GPIO_Output
PA11.Signal=GPIO_Output
PA12.Signal=GPIO_Output
PA4.Signal=ADCx_IN9
PA5.Signal=COMP_DAC12_group
PA6.Signal=ADCx_IN11
PA7.Signal=ADCx_IN12
PA8.Signal=GPIO_Input
PA9.Signal=GPIO_Output
PB0.Signal=GPIO_Output
PB1.Signal=ADCx_IN16
PB10.Signal=GPIO_Output
PB11.Signal=GPXTI11
PB12.Signal=SPI2_NSS
PB13.Signal=SPI2_SCK
PB14.Signal=SPI2_MISO
PB15.Signal=SPI2_MOSI
PB2.Signal=GPIO_Input
PB5.Signal=GPIO_Input
PB6.Signal=I2C1_SCL
PB7.Signal=I2C1_SDA
PC0.Signal=GPIO_Output
PC10.Signal=UART4_TX
PC11.Signal=UART4_RX
PC2.Signal=GPIO_Output
PC3.Signal=GPIO_Output
PC4.Signal=GPIO_Input
PC9.Signal=GPIO_Output

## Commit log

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2022-10-28 OBC changed to STM32L4, pinout added, EPS ported
    [PQ_EPS.kicad_pcb, PQ_EPS.kicad_sch, PQ_OBC&COMMS.kicad_pcb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]
2022-10-29 eps port to kicad corrected
    [PQ_EPS.kicad_pcb, PQ_EPS.kicad_sch]
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2022-11-04 obc rework
    [pq_obc_comms.kicad_pcb, pq_obc_comms.kicad_sch]
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2022-11-09 OBC finished, BoM included and RF traces revised
    [pq_obc_comms.kicad_pcb, pq_obc_comms.kicad_sch]
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2022-11-17 lateral boards added, ADCS schematic lacks mtq drivers
    [PQ_ADCS.kicad_pcb, PQ_Lat_Board.kicad_pcb, PQ_Lat_Board.kicad_sch]
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2022-11-21 killswitch and batt- pins swapped
    [PQ_BotBoard.kicad_pcb, PQ_BotBoard.kicad_sch]
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2023-01-30 EPS LTC 4040 correction and layout revamp
    [PQ_EPS.kicad_pcb, PQ_EPS.kicad_sch]
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2023-01-31 ADCS: added magnetometer, removed Tsens. OBC: Total_Current net removed, Bat_NTC routed to PA0 OBC ADC input. Ymag: centering of the vertical pin
    [PQ_ADCS.kicad_pcb, PQ_ADCS.kicad_sch, PQ_MagYBoard.kicad_pcb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]
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2023-02-13 Solved old design components&library altium import problems. Pre KiCad7
    [PQ_PL2.kicad_pcb, PQ_PL2.kicad_sch]
2023-02-17 Full Kicad7 transition, library improvement and adaptation, correct footprints and 3D models added
    [PQ1_TopBoard.kicad_pcb, PQ1_TopBoard.kicad_sch, PQ1_TopBoard.step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]
2023-03-20 Added adaptive resistive network for battery chemistry and charge voltage flexibility & connected all the PoLs + COMMS to 3V3_perm instead of VCC (3.3V - schottky diode)
    [PQ_EPS.kicad_pcb, PQ_EPS.kicad_sch, PQ_EPS.step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]
2023-03-20 P/L2 V03 final schematic. Replaced the Mixer+VCO+Opamp <- OBC DAC configuration with the MAX2121. Switched the IF from 40 MHz (prone to image frequencies due to passive mixers) to 70 MHz with complex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
    [PQ_PL2.kicad_pcb, PQ_PL2.kicad_sch]
2023-03-22 PoL & SX1262 feeding at 3.3V and OBC feeding at 3.1 (Schottky diode) strategy changed from inner layer 2 plane to 1 mm thick traces
    [pq_obc_comms.kicad_pcb, pq_obc_comms.kicad_sch]
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2023-03-23 P/L2 schematic revision and preliminary layout formulation: tranmission lines and block biasing
    [PQ_PL2.kicad_pcb, PQ_PL2.kicad_sch]
2023-03-28 pl1 ready to manufacture, obc&comms small touches prior to manufacture
    [PQ_PL1.kicad_pcb, pq_obc_comms.kicad_pcb]
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2023-03-29 Payload 2 Schematic and PCB update. Pedning final verification and manufacturing
    [PQ_PL2.kicad_pcb, PQ_PL2.kicad_sch]
2023-03-29 Payload 1 board vertical connector silkscreen annotation correction
    [PQ_PL1.kicad_pcb]
2023-03-29 Finished Payload 2 Schematic + PCB + BOM + Gerber + STEP Version 3.0
    [PQ_PL2.kicad_pcb, PQ_PL2.kicad_sch, PQ_PL2.step]
2023-03-29 Payload 2 V3.1 - Added photodiode, associated Opamp and routing to pin STM PB0
    [PQ_PL2.kicad_pcb, PQ_PL2.kicad_sch, PQ_PL2.step]
2023-03-29 Payload 2 V3.2 - Rounded the RF 90 degree turn between the C3 and J8 probe connector
    [PQ_PL2.kicad_pcb, PQ_PL2.step]
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2023-04-11 Small changes of component fields for the BOM
    [PQ1_TopBoard.kicad_sch, PQ_BotBoard.kicad_sch, PQ_EPS.kicad_sch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]
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2023-04-23 J4 pin was inversed, and traces connected wrongly. Now it is correct. Reorder is needed. F in chat
    [PQ_EPS.kicad_pcb, PQ_EPS.step]
2023-04-24 Added MPPT input pin for testing on board of the EGSE of the PQ nominal operation: Battery and MPPT input both in use
    [PQ_EPS.kicad_pcb, PQ_EPS.kicad_sch, PQ_EPS.step]
2023-07-19 opamp footprint and connections corrected
    [PQ_ADCS.kicad_pcb, PQ_ADCS.kicad_sch]
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2023-10-04 Updated outer boards design as required by the change from Azur Space house-cut solar cells to Lighttricity's S3040_CIC model. Preserved the older design in lat_board_old
    [PQ_BotBoard.kicad_pcb, PQ_BotBoard.kicad_sch, PQ_Lat_Board.kicad_pcb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]
2023-10-11 Updated Production files for the ADCS, LAT and BOT boards for new order
    [PQ_ADCS.kicad_pcb, PQ_BotBoard.kicad_pcb, PQ_Lat_Board.kicad_pcb]
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2023-11-07 Corrected the PL2 5V booster issue (changed the pins of the LT3048-5 to LT3048 & added resistive divider for 5V output)
    [PQ_PL2.kicad_pcb, PQ_PL2.kicad_sch]
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2024-01-10 added CAD assembly with PQ1 and PQ3 configurations
    [Antenna_Tape.SLDPRT, Antenna_Tape_Sheet.SLDPRT, BN 20146 3233654 hexalobular socket head cap screw M2x5.SLDPRT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]
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2024-01-12 solved collission in PL1
    [PQ1_TopBoard.kicad_pcb, pq-pl1-top.step]
2024-01-12 solved wrong connector in lateral board
    [PQ_Lat_Board.kicad_pcb, PQ_Lat_Board.kicad_sch, PQ_Lat_Board.step]
2024-01-12 fixed PL1 and lateral U.FL connector
    [Antenna_Tape_Sheet.SLDPRT, PQ-STRUCTURE-M3_Spacer_Round.SLDPRT, PQ_Lat_Board.SLDPRT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]
2024-04-10 Corrected the U.FL connector footprints on the PL2 Board. Added OBC&COMMS Bom
    [PQ_PL2.kicad_pcb, PQ_PL2.kicad_sch]
2024-04-11 Add names of PQ collaborators in Y magnetorquer
    [PQ_MagYBoard.kicad_pcb, PQ_MagYBoard.kicad_sch]
2024-04-11 fix mirroring of Lightricity's solar cells
    [PQ_BotBoard.kicad_sch, PQ_Lat_Board.kicad_pcb, PQ_Lat_Board.kicad_sch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]
2024-04-11 fix the mirror on the external crystal of the OBC
    [pq_obc_comms.kicad_pcb, pq_obc_comms.kicad_sch]
2024-04-17 ADCS update
    ADCS with magnetometer issue fixed
    [PQ_ADCS.kicad_pcb]
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2024-04-17 Delete PQ_Lat_Board directory
    Error: Incorrect directory added within an incorrect directory.
    [PQ_Lat_Board.kicad_pcb, PQ_Lat_Board.kicad_sch, PQ_Lat_Board.step]
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2024-06-10 Symbol path corrections, X1 crystal mirror correction, J2&J3&J4 name flip PCB
    [pq_obc_comms.kicad_pcb, pq_obc_comms.kicad_sch]
2024-06-10 Altium symbol imports fix, rotated J3, updated track widths for power lines, solved courtyard conflicts, DRC
    [PQ_EPS.kicad_pcb, PQ_EPS.kicad_sch]
2024-06-10 Solved symbol conflicts with old Altium path: U1, U2, U3, J1(7) NC, solved symbol-library-footprint conflicts, reduced number of layers from 6 to 4, reduced GND plane zones from 3 to 1 for all layers
    [PQ_ADCS.kicad_pcb, PQ_ADCS.kicad_sch]
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2024-06-10 J2(2) pin rename to SWO; DRC, fixed missconnection of VGA power to P/L_power pin instead of the generic 3V3_perm
    [PQ_PL1.kicad_pcb, PQ_PL1.kicad_sch]
2024-06-10 Added NSL lektron logo, reconciled library symbol - footprints, moved the picoblade connector so not to conflict with the top structure, fixed VCC trace issue
    [PQ1_TopBoard.kicad_pcb, PQ1_TopBoard.kicad_sch]
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2024-06-10 Removed netie, updated SC footprint, trace reform, logo&name cleanup, footprint reconciled, DRC
    [PQ_Lat_Board.kicad_pcb, PQ_Lat_Board.kicad_sch]
2024-06-10 Removed netie, updated SC footprint, trace reform, logo&name cleanup, footprint reconciled, DRC, centered umbilical connector
    [PQ_BotBoard.kicad_pcb, PQ_BotBoard.kicad_sch]
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2024-06-13 Added a charging protection for the battery using the umbilical (antireturn Schottky diode and LDO) and regenerated the production files
    [PQ_BotBoard.kicad_pcb, PQ_BotBoard.kicad_sch]
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2024-10-06 Recenter components to fit inside the square hole of the slider, change PicoBlade from 2 pins to 3 pins
    [PQ_BotBoard.kicad_pcb, PQ_BotBoard.kicad_sch]
2024-10-08 Re-routed the SC, added new SC symbol in schematic, and added pad to solder the comms antenna inside the lateral.
    [PQ_Lat_Board.kicad_pcb, PQ_Lat_Board.kicad_sch]
2024-10-11 add positive pad behind the Solar Cell to allow soldering the solar cell with epoxy
    [PQ_Lat_Board.kicad_pcb]
2024-10-11 add Lighticity SC to bottom with the option to solder using epoxy
    [PQ_BotBoard.kicad_pcb, PQ_BotBoard.kicad_sch]
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2024-10-21 Recenter holes in Lateral PCB as there was a slight misalignment with the top structure
    [PQ_Lat_Board.kicad_pcb, PQ_Lat_Board.kicad_sch]
2024-10-21 small changes: change ID R5 to Rbias, add snail logo, and swap SOLARZ with GND
    [PQ_EPS.kicad_pcb, PQ_EPS.kicad_sch]
2024-10-21 swap SOLARZ with GND
    [PQ_ADCS.kicad_pcb, PQ_ADCS.kicad_sch]
2024-10-21 change pin RST_DRIVERS to STM32_PA9, swap SCL3 with NC and redirect all IC to new SCL3 location. Change NC pin to PH_PL, substitute PHT6 to PH_PL and small fixes
    [PQ_ADCS.kicad_pcb, PQ_ADCS.kicad_sch]
2024-10-21 change RST_DRIVERS to STM32_PA9, swap SCL3 with NC, and change NC to PH_PL
    [PQ_EPS.kicad_pcb, PQ_EPS.kicad_sch]
2024-10-21 change RST_DRIVERS to STM32_PA9, swap SCL3 with NC and change NC to PH_PL
    [pq_obc_comms.kicad_pcb, pq_obc_comms.kicad_sch]
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2025-11-30 Reduced errors
    [PQ_ADCS.kicad_pcb, PQ_ADCS.kicad_sch]
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2025-12-27 No errors, but still warnings
    [PQ_ADCS.kicad_pcb, PQ_ADCS.kicad_sch]
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2026-01-20 lateral fixed
    [PQ_Lat_Board.kicad_pcb, PQ_Lat_Board.kicad_sch]
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2026-05-18 ADCS_HBRIDGE backup restore
    Restored version with H bridge and no connectors modification
    [PQ_ADCS.kicad_pcb, PQ_ADCS.kicad_sch, PQ_BotBoard-B_Silkscreen.dxf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]
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2026-07-29 NC digital pincs fix
    Unused digital pins as well as I2C pins are now set as not connected instead of grounded. Added lock files to gitignore
    [PQ_ADCS.kicad_pcb, PQ_ADCS.kicad_sch]
2026-08-04 Added Capacitors to HBridge Controllers
    Coupling capacitors added as required by the HBridge controllers.
    [PQ_ADCS.kicad_pcb, PQ_ADCS.kicad_sch]
2026-08-04 Silkscreen Fixes
    [PQ_ADCS.kicad_pcb]
2026-08-06 Fixed ALTIUM imported symbols and thermal relief in PCB
    [PQ_EPS.kicad_pcb, PQ_EPS.kicad_sch]
2026-09-09 Revert "Fixed ALTIUM imported symbols and thermal relief in PCB"
    This reverts commit 59c253d9c9169edb314c96a94842430ce280be70.
    The authoritative EPS design is the local work at f562e89, which this
    branch restores. Reverting to avoid losing it.
    Note that 59c253d was a direct child of f562e89 and did carry the
    killswitch changes forward (R5, KILLSWITCH+ intact). What it changed was
    the symbol library mapping: 20 components moved off the Altium import
    onto stock KiCad symbols (C1/C2/C4/C5/CFx/CINx/CINSNSx/COUTx/COUTSNSx ->
    Device:C, D4-D6 -> Device:D_Schottky) plus an added #FLG01 PWR_FLAG.
    That cleanup is still worth doing and should be redone on top of the
    current EPS design. Related: pq_e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
    [PQ_EPS.kicad_pcb, PQ_EPS.kicad_sch]
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2026-09-09 Import COMMS antenna deployment assembly updates
    Sync assembly/ with the COMMS_Antenna_Deployment working set:
    - Add lateral/antena-deployment/ with the 13 deployment-mechanism
    parts (turret, pivot, spring, clip, jumpers, screws, resistor).
    - Add structure/Bateria LP14430 and Battery Case.
    - Add ieee_grss_pocketqube_beta antena.SLDASM alongside the existing
    top-level assembly rather than replacing it, so the current
    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
    [5108N949_Music Wire Steel Extension Spring with Loop Ends (1).SLDPRT, 5108N95_Music Wire Steel Extension Spring with Loop Ends.SLDPRT, 96605K31_Galvanized Spri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]
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2026-09-28 ADCS corrected and verified. Production ready
    [PQ_ADCS.kicad_pcb, PQ_ADCS.kicad_sch]
2026-09-28 EPS corrected and verified. Production ready
    [PQ_EPS.kicad_pcb, PQ_EPS.kicad_sch]
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2026-09-29 Botboard corrected. Need to be verified
    [PQ_BotBoard.kicad_pcb]
2026-10-07 Botboards and Latbaords corrected and revised. Production ready
    [PQ_BotBoard-B_Silkscreen.dxf, PQ_BotBoard-Edge_Cuts.dxf, PQ_BotBoard-F_Silkscreen.dxf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]
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
